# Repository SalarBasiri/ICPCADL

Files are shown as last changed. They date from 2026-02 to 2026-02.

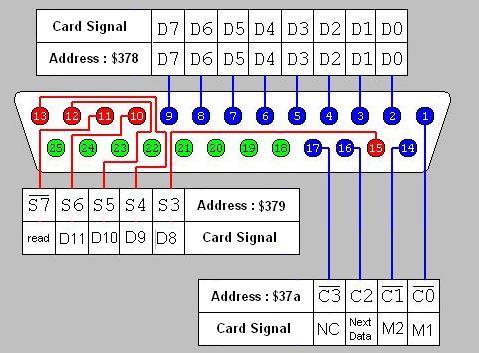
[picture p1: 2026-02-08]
Docs/Pictures/pinout.jpg

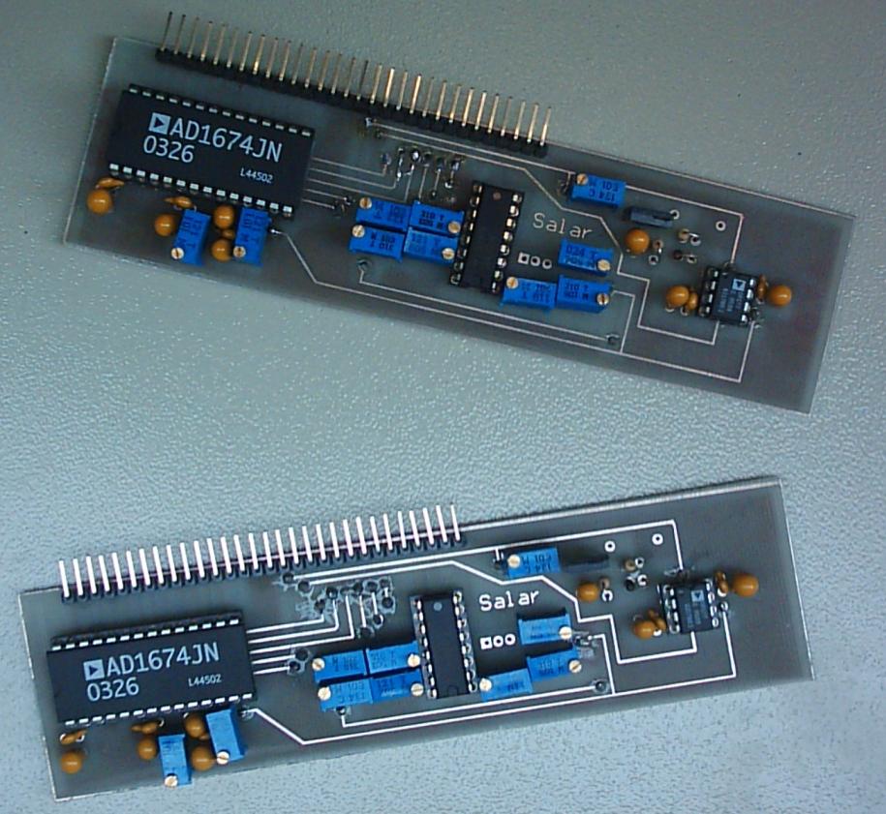
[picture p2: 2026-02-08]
Docs/Pictures/Fig3-5.JPG

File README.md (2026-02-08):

# 8-Channel Synchronous ICP Accelerometer Datalogger

## 📌 Project Overview

Developed in **2005** at **Guilan University**, this project was commissioned by the **Civil Engineering Department** to monitor structural vibrations and seismic behavior in scale models. The system is a complete mechatronics solution featuring custom signal conditioning, multi-MCU firmware, and a Delphi-based control interface.

🎥 [**Watch the System Demonstration on YouTube**](https://www.youtube.com/watch?v=GTqIrTORt20)

----------

## 📺 Demonstration Highlights

The linked video demonstrates the following key aspects of the project:

-   **The Test Setup:** A scale model of a building tower is mounted on a seismic shaker table controlled by an inverter [[00:19](http://www.youtube.com/watch?v=GTqIrTORt20&t=19)].
    
-   **Hardware in Action:** The ICP accelerometer is mounted on the tower, sending signals via BNC cables to the custom datalogger [[01:20](http://www.youtube.com/watch?v=GTqIrTORt20&t=80)].
    
-   **Real-time Software:** The Delphi application is shown configured for sampling, displaying real-time acceleration waveforms [[03:30](http://www.youtube.com/watch?v=GTqIrTORt20&t=210)].
    
-   **Physical Interface:** A look at the physical device featuring the LCD for standalone RMS/Peak monitoring and the 4x4 keypad [[06:06](http://www.youtube.com/watch?v=GTqIrTORt20&t=366)].

----------

## 🛠 Technical Specifications

### **Simultaneous Sample-and-Convert Architecture**

Unlike multiplexed systems, this architecture manages **8 separate AD1674 (12-bit) converters** in parallel.

-   **Synchronicity:** A central AVR "Main Controller" triggers all 8 converters simultaneously to ensure no phase lag between channels—essential for structural modal analysis [[03:05](http://www.youtube.com/watch?v=GTqIrTORt20&t=185)].
    
-   **High-Speed Transfer:** Data is pushed to the PC via the **Parallel Port (EPP Mode)** using custom assembly timing [[08:23](http://www.youtube.com/watch?v=GTqIrTORt20&t=503)].
    
-   **Sampling Rate:** Hardware supports up to **5,000 Samples per Second (5 kS/s)** per channel [[03:37](http://www.youtube.com/watch?v=GTqIrTORt20&t=217)].

### **Signal Conditioning**

-   **ICP Support:** Integrated constant current source (adjustable 2mA to 10mA) to power the internal electronics of piezoelectric sensors [[00:55](http://www.youtube.com/watch?v=GTqIrTORt20&t=55)].
    
-   **Programmable Gain:** Gain levels from **1 to 2200** are software-selectable, managed by a dedicated AVR controller and CD4051 analog muxes [[04:10](http://www.youtube.com/watch?v=GTqIrTORt20&t=250)].
    
-   **Digital Filtering:** The software includes an **FIR (Finite Impulse Response)** filter with a selectable cutoff frequency (8Hz to 500Hz) to eliminate high-frequency noise [[04:45](http://www.youtube.com/watch?v=GTqIrTORt20&t=285)].

----------

## 📁 Repository Structure

-   `/Software_Delphi`: Source code for the Windows XP desktop application.
    
-   `/Firmware_AVR`: BASCOM source code for the three-controller architecture (Main, Gain, and LCD/UI) [[06:58](http://www.youtube.com/watch?v=GTqIrTORt20&t=418)].
    
-   `/Hardware_Design`: Schematics and PCB layouts.
    
-   `/Docs`: The original Khwarizmi Young Award report and technical paper.

----------

## ⚠️ Legacy Note

This system was designed for Windows XP. It utilizes the **PortTalk** driver (`porttalk.sys` and `allowio.exe`) to perform direct hardware I/O via the Parallel Port [[08:23](http://www.youtube.com/watch?v=GTqIrTORt20&t=503)]. Modern 64-bit Windows versions will require hardware-level emulation or legacy environments to run the software.

----------

## 🎓 Credits

-   **Developer:** Salar Basiri (Mechanical Engineering)
    
-   **Supervision:** Dr. Fallah, Guilan University [[09:50](http://www.youtube.com/watch?v=GTqIrTORt20&t=590)]
    
-   **Partnership:** Faculty of Engineering, Civil Engineering Department

**Security & Licensing Implementation:** The production version of the software featured a custom-built hardware USB lock (Dongle) system to restrict usage to authorized workstations at Guilan University. A "Debug/Unlocked" version is included in this repository for archival and demonstration purposes.

---

## ⚖️ License & Copyright

Copyright (c) 2005-2024 Salar Basiri

This project is licensed under the **MIT License**. 

Permission is hereby granted, free of charge, to any person obtaining a copy of this software and associated documentation files (the "Software"), to deal in the Software without restriction, including without limitation the rights to use, copy, modify, merge, publish, distribute, sublicense, and/or sell copies of the Software, and to permit persons to whom the Software is furnished to do so, subject to the following conditions:

The above copyright notice and this permission notice shall be included in all copies or substantial portions of the Software.

THE SOFTWARE IS PROVIDED "AS IS", WITHOUT WARRANTY OF ANY KIND, EXPRESS OR IMPLIED, INCLUDING BUT NOT LIMITED TO THE WARRANTIES OF MERCHANTABILITY, FITNESS FOR A PARTICULAR PURPOSE AND NONINFRINGEMENT.

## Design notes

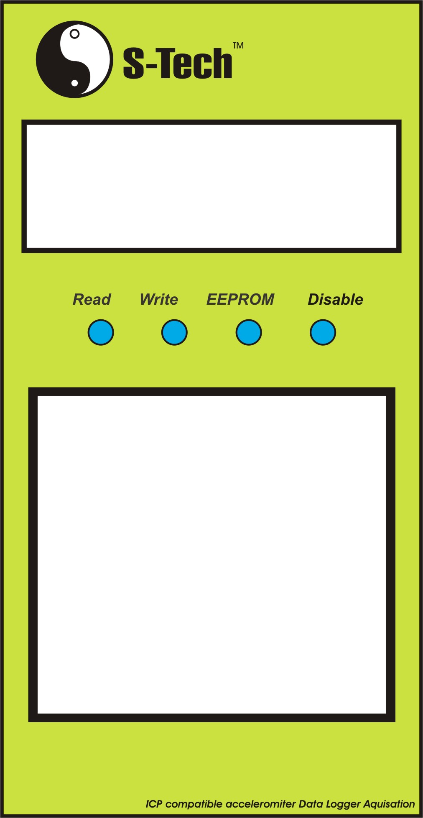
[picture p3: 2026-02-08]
Hardware_Design/Panel/Graphic1.jpg

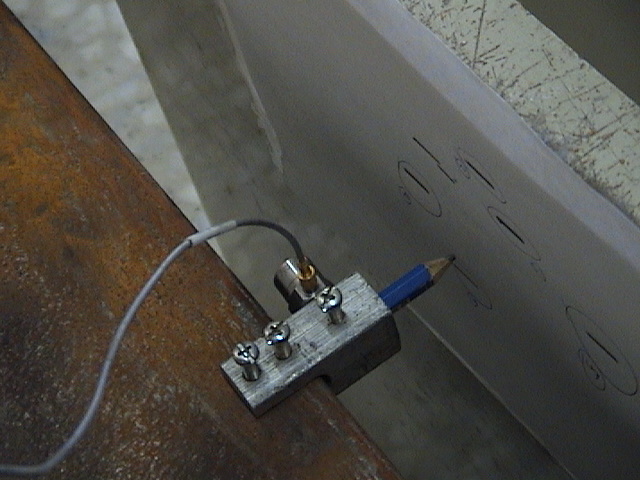
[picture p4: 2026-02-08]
Docs/Pic By Handy CAM/Copy of DSC00218.JPG

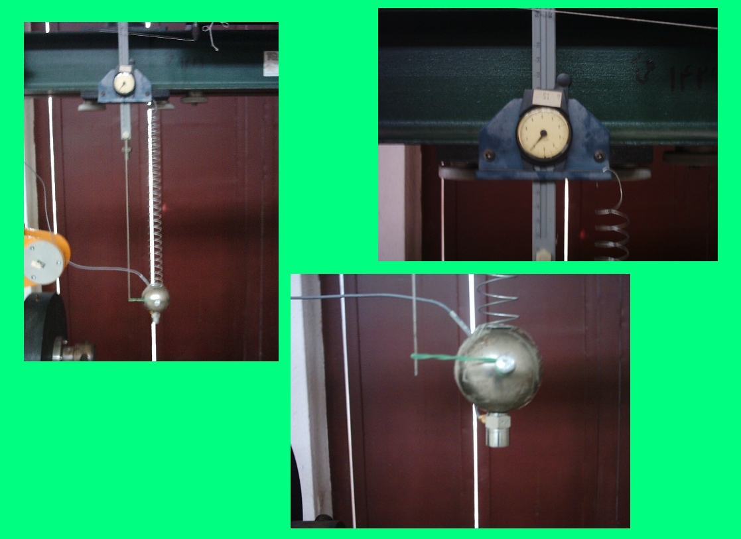
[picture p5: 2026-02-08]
Docs/Pictures/Fig5-1e.JPG

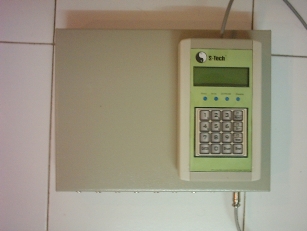
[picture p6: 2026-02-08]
Docs/Pictures/Fig-1.JPG

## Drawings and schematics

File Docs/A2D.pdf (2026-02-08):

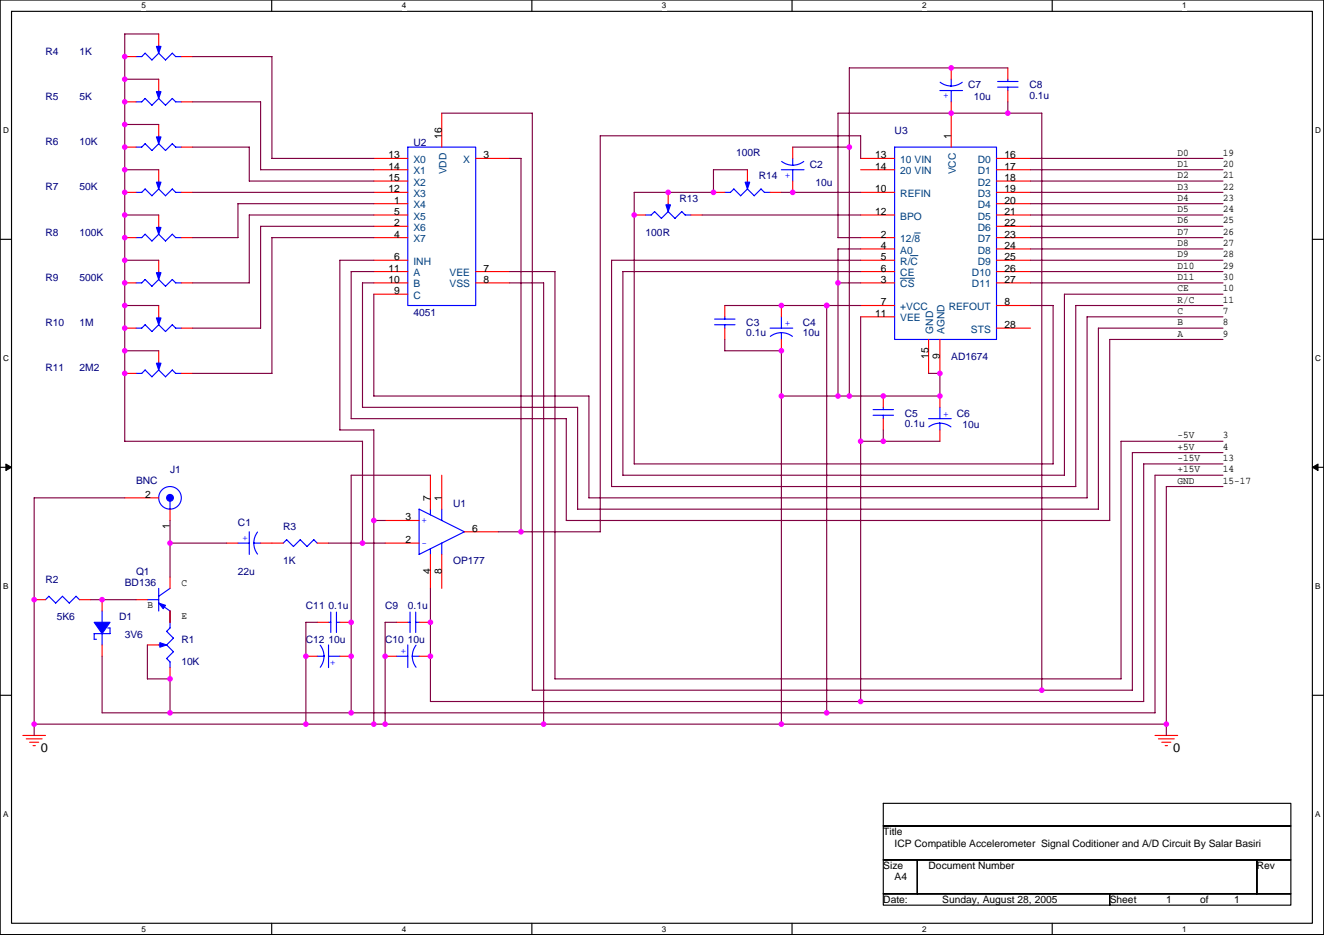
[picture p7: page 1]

Title
ICP Compatible Accelerometer Signal Coditioner and A/D Circuit By Salar Basiri

Size A4 | Document Number | Rev

Date: Sunday, August 28, 2005 | Sheet 1 of 1

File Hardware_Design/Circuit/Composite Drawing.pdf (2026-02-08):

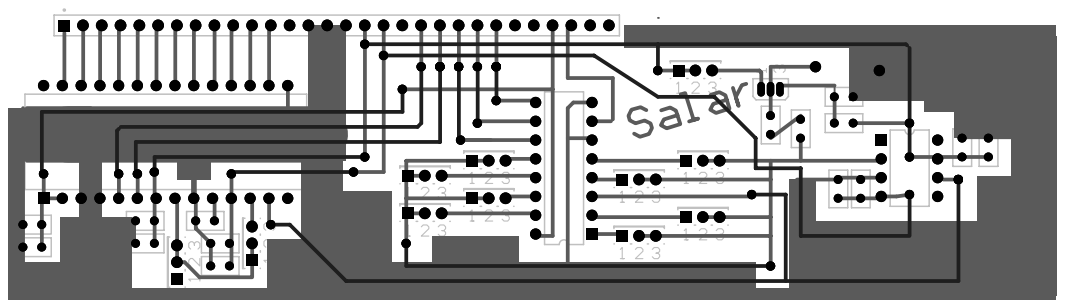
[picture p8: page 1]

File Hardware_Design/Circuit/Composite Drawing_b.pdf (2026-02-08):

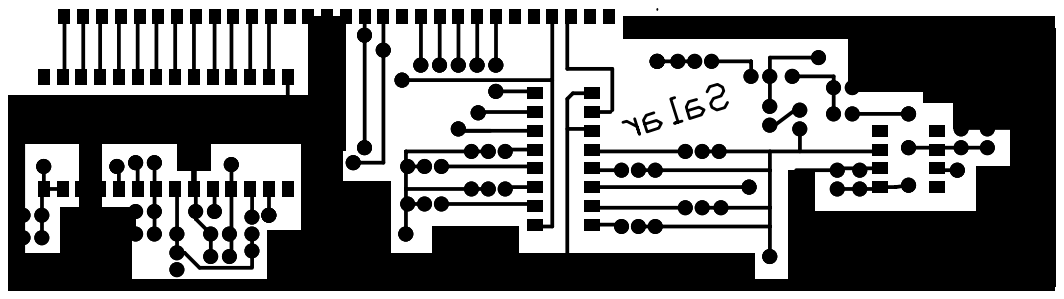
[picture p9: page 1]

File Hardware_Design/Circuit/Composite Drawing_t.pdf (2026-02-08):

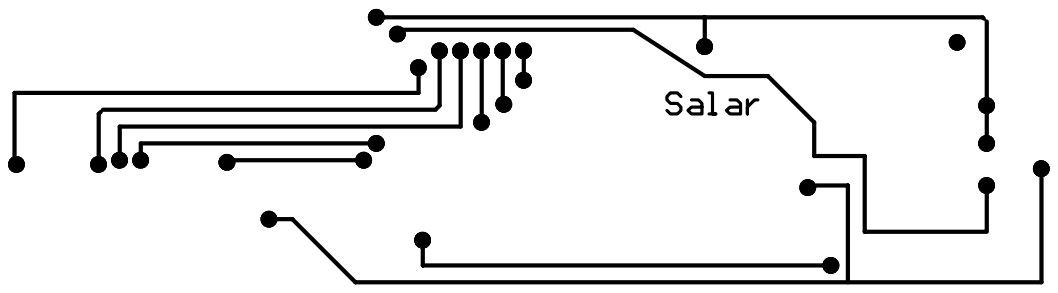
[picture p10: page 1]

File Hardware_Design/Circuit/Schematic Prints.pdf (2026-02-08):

# Power

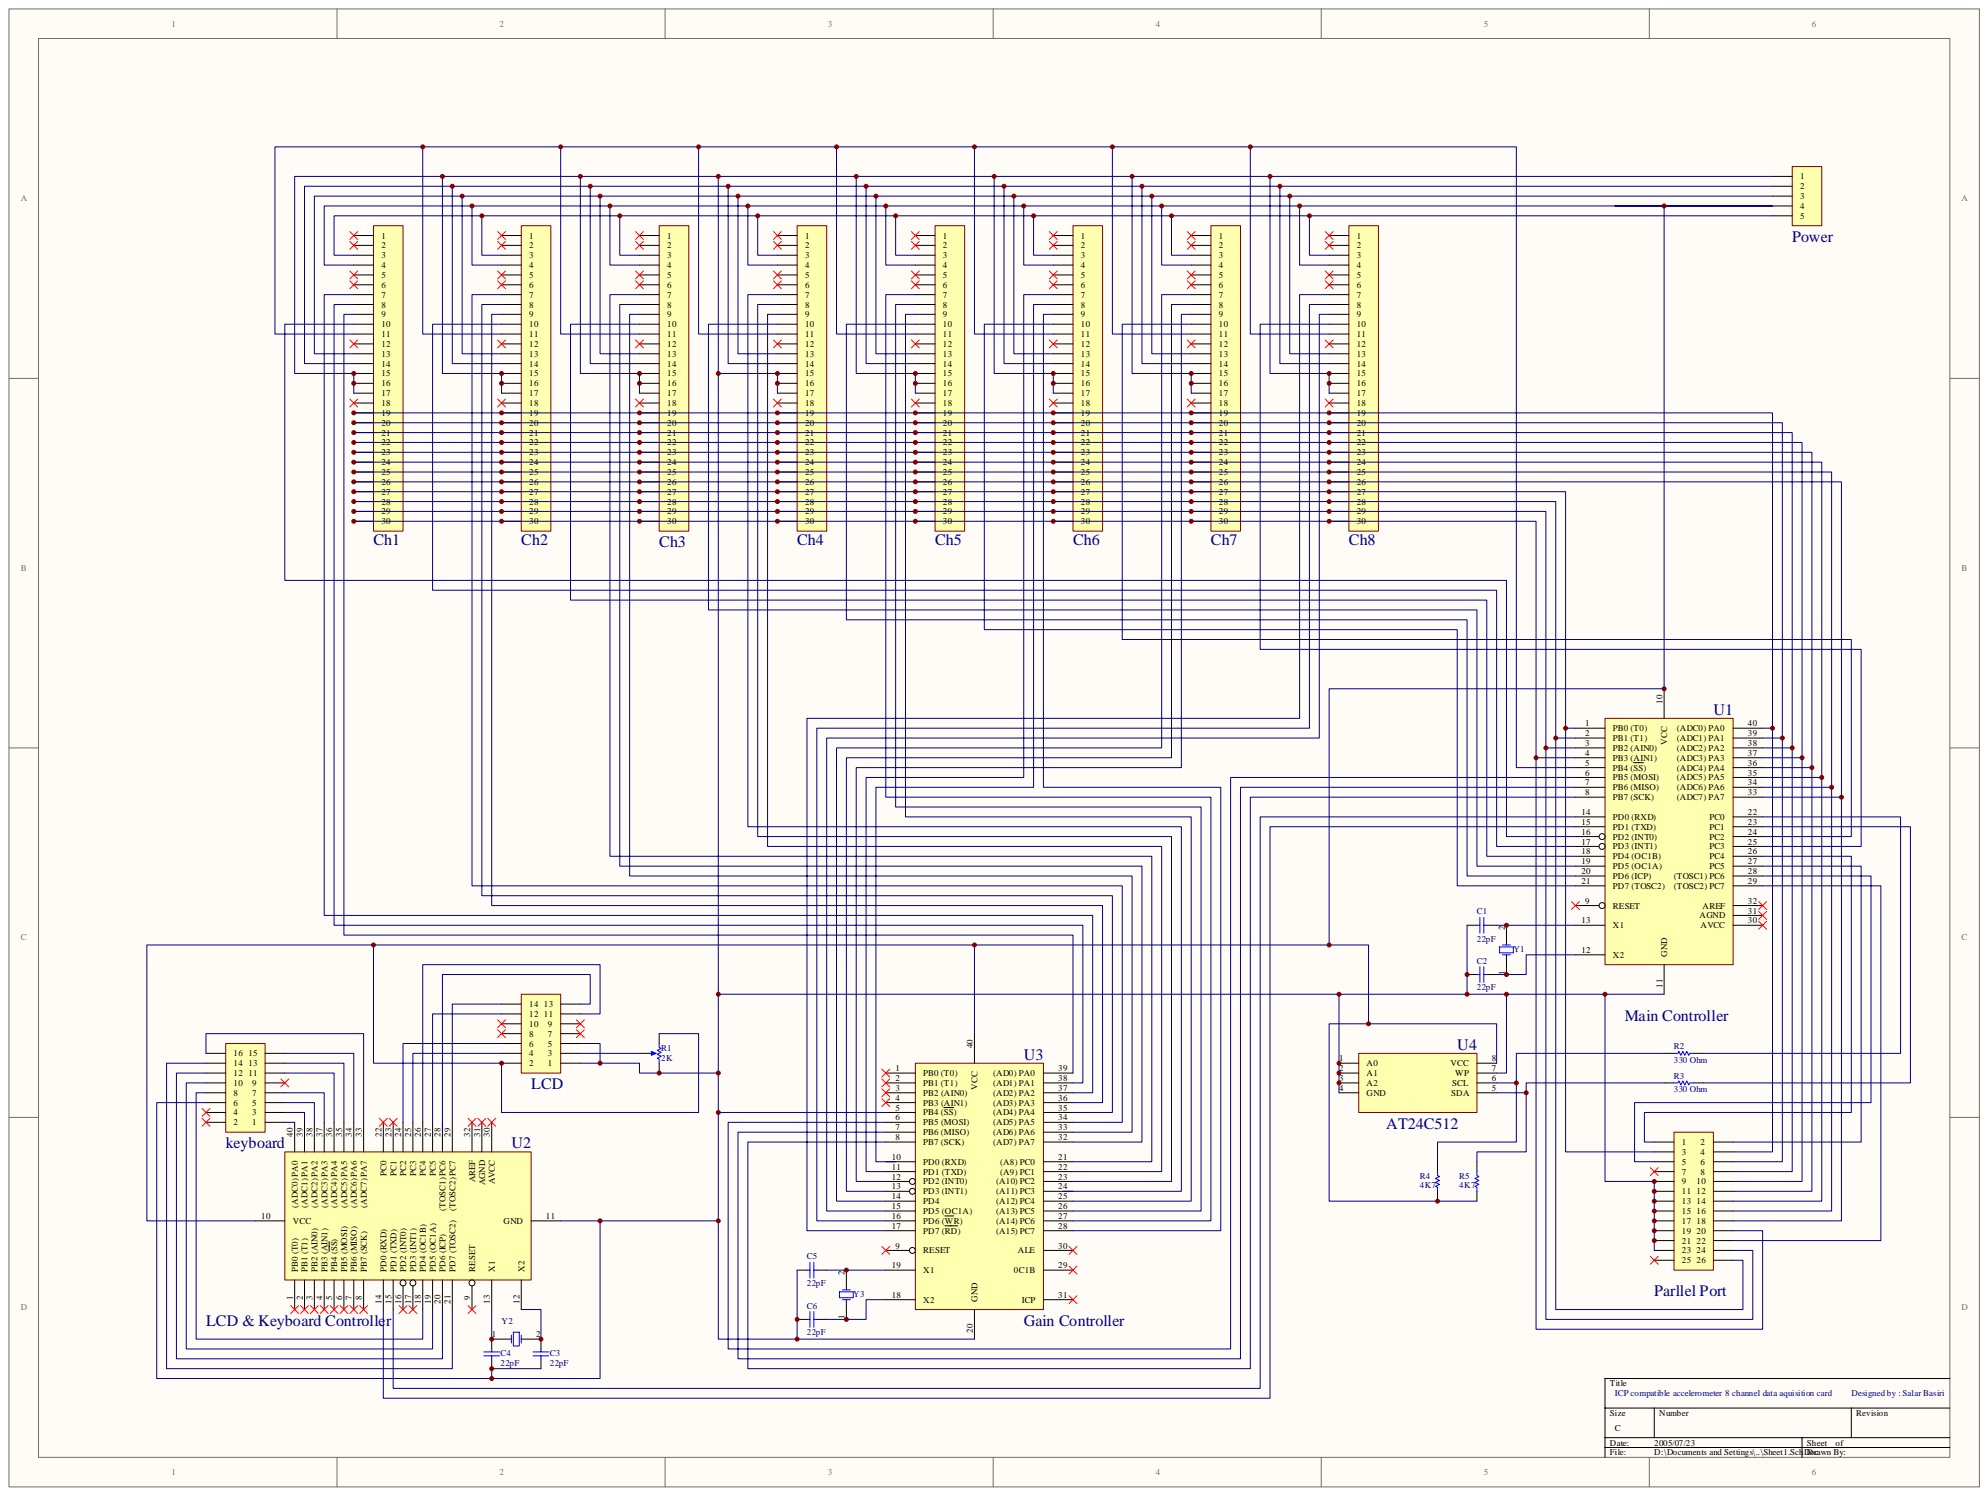
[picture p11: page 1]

20 | 20 | | 20 | | 20 | 20 | | 20 | 20 | 20
21 | 21 | 21 | 21 | 21 | 21 | 21 | 21
22 | 22 | | 22 | | 22 | 22 | | 22 | 22 | 22
23 | 23 | 23 | 23 | 23 | 23 | 23 | 23
24 | 24 | | 24 | | 24 | 24 | | 24 | 24 | 24
25 | 25 | 25 | 25 | 25 | 25 | 25 | 25
26 | 26 | | 26 | | 26 | 26 | | 26 | 26 | 26
27 | 27 | 27 | 27 | 27 | 27 | 27 | 27
28 | 28 | | 28 | | 28 | 28 | | 28 | 28 | 28
29 | 29 | 29 | 29 | 29 | 29 | 29 | 29
30 | 30 | | 30 | | 30 | 30 | | 30 | 30 | 30

C | | PB3 (AIN1) 4 | (ADC3) PA3 (ADC4) PA4 (ADC7) PA7 PC0 PC1 PC3 PC4 PC5 (TOSC1) PC6 (TOSC2) PC7 | 37 29 PD7 (TOSC2) 21 | C

PB2 (AIN0) 3 | 38

(ADC2) PA2

PB6 (MISO) 7
PB7 (SCK) 8 | 33

PD1 (TXD) 15 PD0 (RXD) 14 | 22

PD2 (INT0) 16
PD3 (INT1) 17 | 25
PD4 (OC1B) 18 | 26
PD5 (OC1A) 19 | 27
PD6 (ICP) 20 | 28

Title ICP compatible accelerometer 8 channel data aquisition card | Designed by : Salar Basiri

Size C | Number | Revision

Date: | 2005/07/23 | Sheet of
File: | D:\Documents and Settings\..\Sheet1.SchDoc Drawn By:

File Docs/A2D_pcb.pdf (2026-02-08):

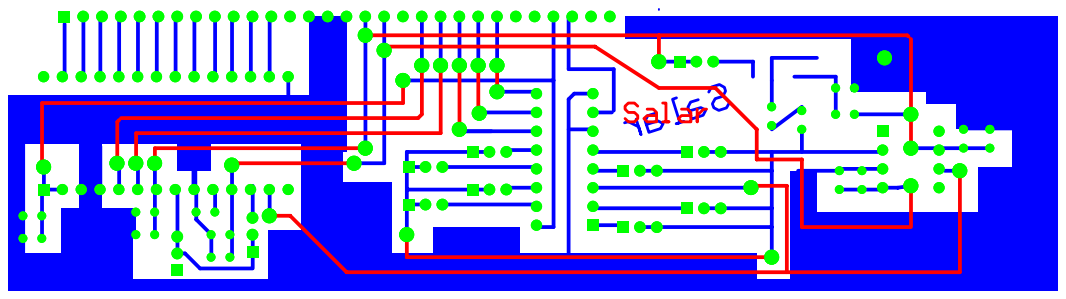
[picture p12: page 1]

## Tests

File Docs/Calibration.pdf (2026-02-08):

## تحليل فرکانسی ارتعاشات آزاد سازه مدل

در ایـن آزمـایش هـدف بدسـت آوردن فرکانـسهای مـدهای ارتعاشـی سـازه ميباشـد. سنسور شتاب به طبقات اول تا چهارم وصـل شـد و بـه طبقـه چهـارم یـک تغييـر مکـان اعمال شده و سپس رها شده است.سيگنال شتاب توسط دستگاه به مـدت ٣٠ ثانيـه جمع آوری شده و سپس توسط MATLAB تحليـل فرکانـسی در بـازه زمـانی ١٠ تـا ٢٠ ثانيه انجام گردیده است. برای تست کنالهای ورودی مختلف سنسو به کانالهای ١ و ٢ و ۶ متصل گردید و نمونه برداری انجام شد مولفه های بدست آمده به تر تيب نزولـی و برای کانالهای مختلف در زیر آمده است.

کانال ١ ١٨٫١ ١۴٫۵ ٨٫١ ٢٫۶
طبقه اول کانال ٢ ١٨٫١ ١۴٫٢ ٨٫۶ ٢٫۶ کانال ٣ ١٨٫١ ١۴٫۴ ٨٫۶ ٢٫۶
کانال ١ ١٨٫١ ٢٫۶ ٧٫٨ ١۴٫۵
طبقه دوم کانال ٢ ١٨٫١ ٢٫۶ ٨٫۶ ١۴٫۵ کانال ٣ ١٨ ٢٫۶ ٨ ١۴٫۵
کانال ١ ١٨٫١ ٢٫۶ ١۴٫٣ ٧٫٩
طبقه سوم کانال ٢ ١٨٫١ ٢٫۶ ١۴٫۴ ٧٫٩ کانال ٣ ١٨٫١ ٢٫۶ ١۴٫۵ ٧٫٩
کانال ١ ١٨٫٢ ٢٫۶ ٨ ١۴٫۵
طبقه چهارم کانال ٢ ١٨٫١ ١۴٫۴ ٢٫۶ ٧٫٨ کانال ٣ ١٨٫١ ٢٫۶ ٧٫٨ ١۴٫۴
جدول ١ – فرکانسهای موجود در سيگنال شتاب طبقات مختلف

در ادامه نمودار محتوای فرکانسی طبقات مختلف آورده شده است. تنظيمات کـارت بـه صورت زیر بوده است:
فرکانس نمونه برداری : s/S ۵٠٠٠ ضریب بهره تقویت سيگنال : ٨٠ فرکانس قطع فيلتر FIR : Hz١٠٠ زمان نمونه برداری : sec٣٠

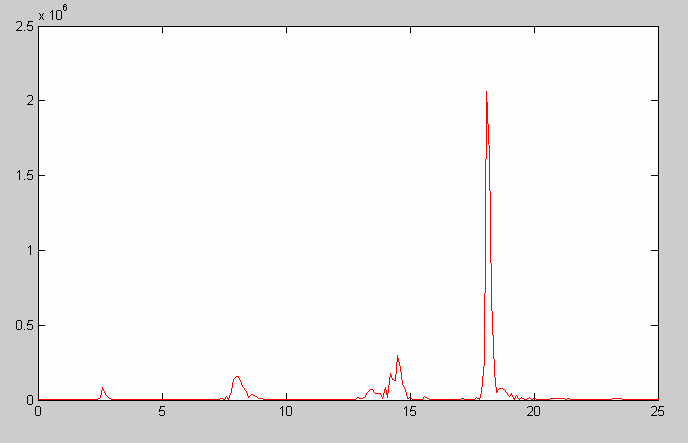
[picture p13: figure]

شکل١ - محتوی فرکانسی سيگنال شتاب طبقه اول

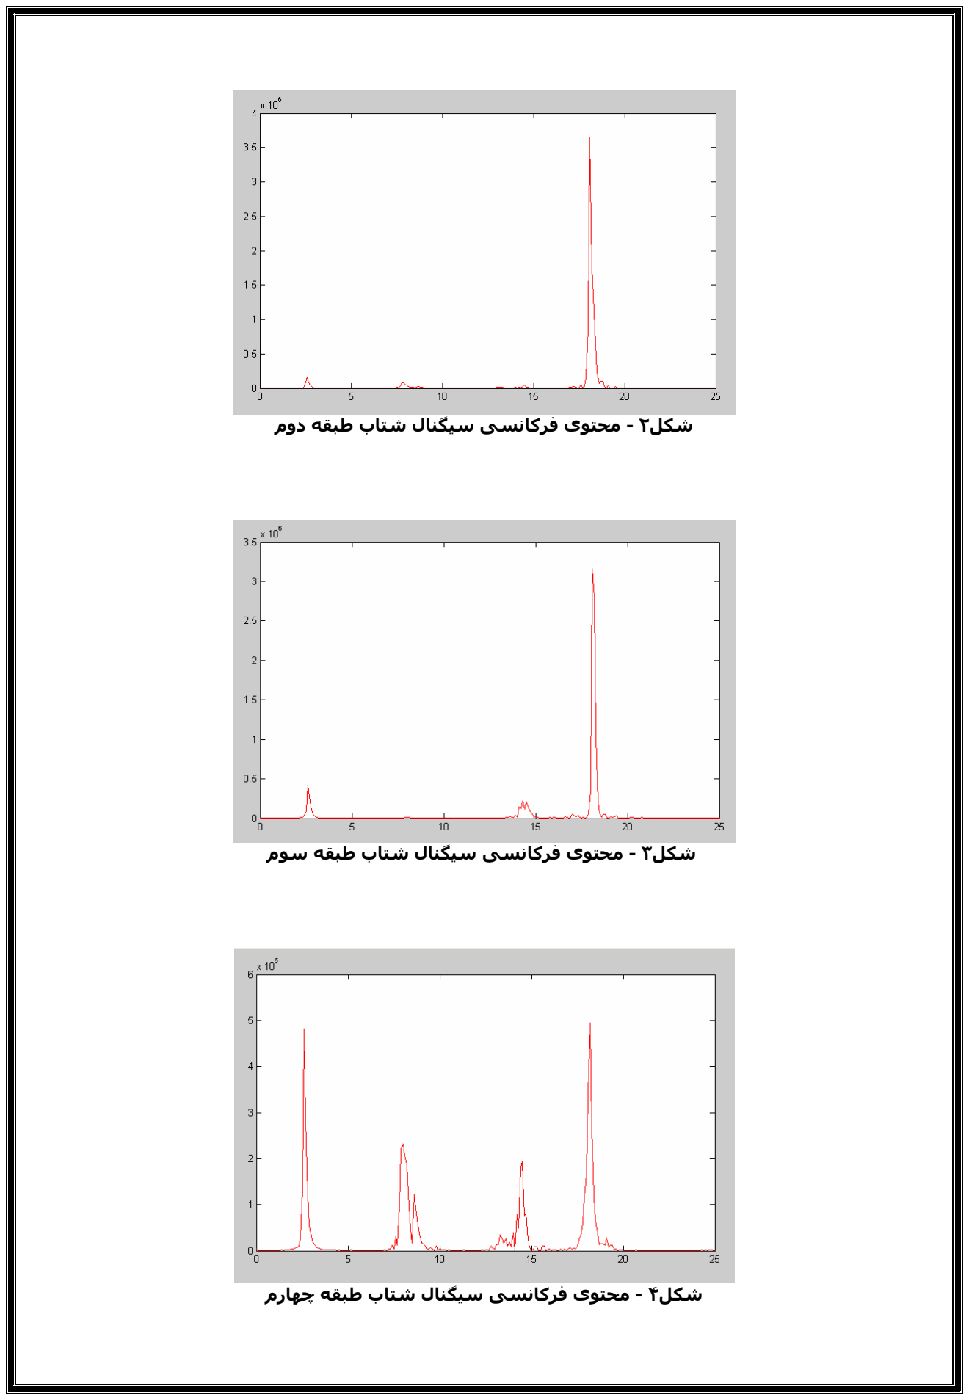
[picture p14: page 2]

شکل٢ - محتوی فرکانسی سيگنال شتاب طبقه دوم

شکل٣ - محتوی فرکانسی سيگنال شتاب طبقه سوم

شکل۴ - محتوی فرکانسی سيگنال شتاب طبقه چهارم

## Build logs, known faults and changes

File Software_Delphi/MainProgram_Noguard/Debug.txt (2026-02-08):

2005/07/19 
11:01:36 È.Ù 
Original File name: E:\New Project\Main_Program\ICPCLDL.dpr
----------------------------------------------------
  Input  string  : UNIT1.DFM
----------------------------------------------------
  Input  string  : UNIT2.DFM
---------------------------------------------------
Raw filenames in selection list
UNIT1.DFM
UNIT2.DFM
---------------------------------------------------

---------------------------------------------------------
Filename passed to ProcessDelphiForm :UNIT1.DFM
Filename passed back to ConvertDRM_to_TXT :UNIT1.DFM
Command string = 'COMMAND.COM /C D:\PROGRA~1\Borland\Delphi7\Bin\convert.exe UNIT1.DFM'
File conversion in ConvertDRM_to_TXT ...
   Filename$       :E:\NEWPRO~1\MAIN_P~1\UNIT1.DFM
       TextFileName:E:\NEWPRO~1\MAIN_P~1\UNIT1.TXT
 Final TextFileName:E:\NEWPRO~1\MAIN_P~1\UNIT1.TXT
Filename passed back to ProcessDelphiForm :E:\NEWPRO~1\MAIN_P~1\UNIT1.TXT

---------------------------------------------------------
Filename passed to ProcessDelphiForm :UNIT2.DFM
Filename passed back to ConvertDRM_to_TXT :UNIT2.DFM
Command string = 'COMMAND.COM /C D:\PROGRA~1\Borland\Delphi7\Bin\convert.exe UNIT2.DFM'
File conversion in ConvertDRM_to_TXT ...
   Filename$       :E:\NEWPRO~1\MAIN_P~1\UNIT2.DFM
       TextFileName:E:\NEWPRO~1\MAIN_P~1\UNIT2.TXT
 Final TextFileName:E:\NEWPRO~1\MAIN_P~1\UNIT2.TXT
Filename passed back to ProcessDelphiForm :E:\NEWPRO~1\MAIN_P~1\UNIT2.TXT

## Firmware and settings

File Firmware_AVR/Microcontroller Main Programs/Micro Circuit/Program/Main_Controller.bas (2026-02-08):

$regfile = "m32def.dat"
$crystal = 8000000
$baud = 1200
Config Serialin = Buffered , Size = 5
Config Serialout = Buffered , Size = 5
Config Timer1 = Timer , Prescale = 1
Config Spi = Hard , Interrupt = Off , Data Order = Lsb , Master = Yes_
                                   , Polarity = High , Phase = 0 , Clockrate = 128
Config Pina.0 = Input
Config Pina.1 = Input
Config Pina.2 = Input
Config Pina.3 = Input
Config Pina.4 = Input
Config Pina.5 = Input
Config Pina.6 = Input
Config Pina.7 = Input
Config Pinb.0 = Input
Config Pinb.1 = Input
Config Pinb.2 = Input
Config Pinb.3 = Input
Config Pinb.4 = Input
Config Pinb.5 = Input
Config Pinb.6 = Input
Config Pinb.7 = Input
Config Pinc.7 = Output
Config Pinc.6 = Input
Config Pinc.5 = Input
Config Pinc.4 = Input
Config Pind.2 = Output
Config Pind.3 = Output
Config Pind.4 = Output
Config Pind.5 = Output
Config Pind.6 = Output
Config Pind.7 = Output
Config Pinc.2 = Output
Config Pinc.3 = Output
Config Pinb.4 = Output

Enable Interrupts
Enable Timer1
Enable Ovf1
On Ovf1 Ovf1rtn
Spiinit
Dim C As Byte
Dim Send As Byte
Dim A As Byte
Dim D(10) As Byte
Dim Timer_start_value As Word

Timer1 = 63935

Disable Timer1
Reset Portc.7

A = Waitkey()
If A = 100 Then Goto Pc
If A = 200 Then Goto Stand_alone
Pc:

Do
If Pinc.5 = 1 Then If Pinc.4 = 0 Then Gosub Read_from_card
If Pinc.5 = 0 Then If Pinc.4 = 1 Then Gosub Write_to_card
If Pinc.5 = 1 Then If Pinc.4 = 1 Then Gosub Read_from_eeprom
If Pinc.5 = 0 Then If Pinc.4 = 0 Then Gosub Card_disable
Loop

Stand_alone:



End                                                         'end program

'*************************   Sample   ********************
Ovf1rtn:

Disable Interrupts
Timer1 = Timer_start_value
Portd = Portd And &B00000011
Reset Portc.2
Reset Portc.3
Set Portb.4

Send = 4
Portd = Portd Or Send
Set Portc.7

For C = 1 To 5
Bitwait Pinc.6 , Set
If Pinc.5 = 0 Then
If Pinc.4 = 0 Then
Send = 40
Printbin Send
Disable Timer1
Portd = Portd And &B00000011
Reset Portc.2
Reset Portc.3
Reset Portc.7
Reset Portb.4
Goto Pc
End If
End If

Shift Portd , Left , 1
Bitwait Pinc.6 , Reset
Next C

Reset Portc.7

Bitwait Pinc.6 , Set
Reset Portd.7
Set Portc.2
Bitwait Pinc.6 , Reset

Bitwait Pinc.6 , Set
Reset Portc.2
Set Portc.3
Bitwait Pinc.6 , Reset

Bitwait Pinc.6 , Set

Reset Portc.3
Reset Portb.4
Portd = Portd Or &B11111100
Set Portc.2
Set Portc.3

Bitwait Pinc.6 , Reset
Enable Interrupts



Return





'************************   read from card   ********************
Read_from_card:
If Send <> 10 Then
  Send = 10
  Printbin Send
  Enable Interrupts
  Enable Timer1


End If


Return




'************************   write to card   ********************
Write_to_card:
If Send <> 20 Then
  Send = 20
  Printbin Send

  For C = 1 To 10
    Bitwait Pinc.6 , Set
    D(c) = Pina
    Bitwait Pinc.6 , Reset
  Next C

  For C = 1 To 8
    Spiout D(c) , 1
    Waitms 100
  Next C

  Select Case D(9)
    Case 1 : Timer_start_value = 63935
    Case 2 : Timer_start_value = 61535
    Case 3 : Timer_start_value = 57535
    Case 4 : Timer_start_value = 45535
    Case 5 : Timer_start_value = 25535
  End Select



End If
Return



'************************   read from EEPROM   ********************
Read_from_eeprom:
If Send <> 30 Then
  Send = 30
  Printbin Send
End If
Return


'************************   card disable   ********************
Card_disable:
If Send <> 40 Then
  Send = 40
  Printbin Send
  Disable Timer1
  Portd = Portd And &B00000011
  Reset Portc.2
  Reset Portc.3
  Reset Portc.7
  Reset Portb.4

End If
Return

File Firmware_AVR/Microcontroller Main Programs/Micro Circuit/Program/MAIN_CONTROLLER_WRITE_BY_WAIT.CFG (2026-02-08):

[COMPILER-CHIP]
Chip=17
XRAM=0
Waitstate=0
XA=0
Stacksize=32
Framesize=16
Sstack=8

[COMPILER-OUTPUT]
Report vars=0
Optimize=0
Binary File=1
Hexadecimal File=1
Report File=1
Debug File=1
Error File=1
ASM File=0
LST File=0
OBJ File=1
SWAP File=0

[COMPILER-COMMUNICATION]
Baudrate=1200
Baudrate1=9600
Frequency=8000000

[COMPILER-I2C]
Scl=0
Sda=0

[COMPILER-LCD]
DB7=PORTB.7
DB6=PORTB.6
DB5=PORTB.5
DB4=PORTB.4
E=PORTB.3
RS=PORTB.2
LCD=1
BUS mode=0
DATA mode=0
LCD address=C000
LCD-RS=8000

[COMPILER-MISC]
Size Warning=0
1wire=PORTB.0

[COMPILER-SPI]
HW SPI=0
SPICLOCK=13
SPISS=13
SPIMOSI=14
SPIMISO=15

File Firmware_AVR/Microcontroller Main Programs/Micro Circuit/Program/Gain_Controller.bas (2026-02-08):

$regfile = "m8515.dat"
$crystal = 8000000
Config Spi = Hard , Interrupt = On , Data Order = Lsb , _
      Master = No , Polarity = High , Phase = 0 , Clockrate = 128
Config Pina.0 = Output
Config Pina.1 = Output
Config Pina.2 = Output
Config Pina.3 = Output
Config Pina.4 = Output
Config Pina.5 = Output
Config Pina.6 = Output
Config Pina.7 = Output
Config Pinc.0 = Output
Config Pinc.1 = Output
Config Pinc.2 = Output
Config Pinc.3 = Output
Config Pinc.4 = Output
Config Pinc.5 = Output
Config Pinc.6 = Output
Config Pinc.7 = Output
Config Pind.0 = Output
Config Pind.1 = Output
Config Pind.2 = Output
Config Pind.3 = Output
Config Pind.4 = Output
Config Pind.5 = Output
Config Pind.6 = Output
Config Pind.7 = Output
Dim Gain_ch(9) As Byte
Dim C As Byte , G As Byte
Enable Interrupts
Enable Spi
On Spi Setting_gain
Spiinit
'Porta = 0
'Portc = 0
'Portd = 0
Reset Porta.0
Reset Porta.1
Reset Porta.2
Reset Porta.3
Reset Porta.4
Reset Porta.5
Reset Porta.6
Reset Porta.7
Reset Portc.0
Reset Portc.1
Reset Portc.2
Reset Portc.3
Reset Portc.4
Reset Portc.5
Reset Portc.6
Reset Portc.7
Reset Portd.0
Reset Portd.1
Reset Portd.2
Reset Portd.3
Reset Portd.4
Reset Portd.5
Reset Portd.6
Reset Portd.7
C = 1
Cls
Do


Loop

End                                                         'end program


Setting_gain:
Disable Interrupts
Gain_ch(c) = Spdr
C = C + 1
If C = 9 Then
'Cls
'For G = 1 To 8
'Lcd Gain_ch(g) ; "  "
'Next G
C = 1
Spiinit
If Gain_ch(1) = 0 Then
Reset Porta.0
Reset Porta.1
Reset Porta.2
End If
If Gain_ch(1) = 1 Then
Set Porta.0
Reset Porta.1
Reset Porta.2
End If
If Gain_ch(1) = 2 Then
Reset Porta.0
Set Porta.1
Reset Porta.2
End If
If Gain_ch(1) = 3 Then
Set Porta.0
Set Porta.1
Reset Porta.2
End If
If Gain_ch(1) = 4 Then
Reset Porta.0
Reset Porta.1
Set Porta.2
End If
If Gain_ch(1) = 5 Then
Set Porta.0
Reset Porta.1
Set Porta.2
End If
If Gain_ch(1) = 6 Then
Reset Porta.0
Set Porta.1
Set Porta.2
End If
If Gain_ch(1) = 7 Then
Set Porta.0
Set Porta.1
Set Porta.2
End If
If Gain_ch(2) = 0 Then
Reset Porta.3
Reset Porta.4
Reset Porta.5
End If
If Gain_ch(2) = 1 Then
Set Porta.3
Reset Porta.4
Reset Porta.5
End If
If Gain_ch(2) = 2 Then
Reset Porta.3
Set Porta.4
Reset Porta.5
End If
If Gain_ch(2) = 3 Then
Set Porta.3
Set Porta.4
Reset Porta.5
End If
If Gain_ch(2) = 4 Then
Reset Porta.3
Reset Porta.4
Set Porta.5
End If
If Gain_ch(2) = 5 Then
Set Porta.3
Reset Porta.4
Set Porta.5
End If
If Gain_ch(2) = 6 Then
Reset Porta.3
Set Porta.4
Set Porta.5
End If
If Gain_ch(2) = 7 Then
Set Porta.3
Set Porta.4
Set Porta.5
End If
If Gain_ch(3) = 0 Then
Reset Porta.6
Reset Porta.7
Reset Portc.0
End If
If Gain_ch(3) = 1 Then
Set Porta.6
Reset Porta.7
Reset Portc.0
End If
If Gain_ch(3) = 2 Then
Reset Porta.6
Set Porta.7
Reset Portc.0
End If
If Gain_ch(3) = 3 Then
Set Porta.6
Set Porta.7
Reset Portc.0
End If
If Gain_ch(3) = 4 Then
Reset Porta.6
Reset Porta.7
Set Portc.0
End If
If Gain_ch(3) = 5 Then
Set Porta.6
Reset Porta.7
Set Portc.0
End If
If Gain_ch(3) = 6 Then
Reset Porta.6
Set Porta.7
Set Portc.0
End If
If Gain_ch(3) = 7 Then
Set Porta.6
Set Porta.7
Set Portc.0
End If
If Gain_ch(4) = 0 Then
Reset Portc.1
Reset Portc.2
Reset Portc.3
End If
If Gain_ch(4) = 1 Then
Set Portc.1
Reset Portc.2
Reset Portc.3
End If
If Gain_ch(4) = 2 Then
Reset Portc.1
Set Portc.2
Reset Portc.3
End If
If Gain_ch(4) = 3 Then
Set Portc.1
Set Portc.2
Reset Portc.3
End If
If Gain_ch(4) = 4 Then
Reset Portc.1
Reset Portc.2
Set Portc.3
End If
If Gain_ch(4) = 5 Then
Set Portc.1
Reset Portc.2
Set Portc.3
End If
If Gain_ch(4) = 6 Then
Reset Portc.1
Set Portc.2
Set Portc.3
End If
If Gain_ch(4) = 7 Then
Set Portc.1
Set Portc.2
Set Portc.3
End If
If Gain_ch(5) = 0 Then
Reset Portc.4
Reset Portc.5
Reset Portc.6
End If
If Gain_ch(5) = 1 Then
Set Portc.4
Reset Portc.5
Reset Portc.6
End If
If Gain_ch(5) = 2 Then
Reset Portc.4
Set Portc.5
Reset Portc.6
End If
If Gain_ch(5) = 3 Then
Set Portc.4
Set Portc.5
Reset Portc.6
End If
If Gain_ch(5) = 4 Then
Reset Portc.4
Reset Portc.5
Set Portc.6
End If
If Gain_ch(5) = 5 Then
Set Portc.4
Reset Portc.5
Set Portc.6
End If
If Gain_ch(5) = 6 Then
Reset Portc.4
Set Portc.5
Set Portc.6
End If
If Gain_ch(5) = 7 Then
Set Portc.4
Set Portc.5
Set Portc.6
End If
If Gain_ch(6) = 0 Then
Reset Portc.7
Reset Portd.0
Reset Portd.1
End If
If Gain_ch(6) = 1 Then
Set Portc.7
Reset Portd.0
Reset Portd.1
End If
If Gain_ch(6) = 2 Then
Reset Portc.7
Set Portd.0
Reset Portd.1
End If
If Gain_ch(6) = 3 Then
Set Portc.7
Set Portd.0
Reset Portd.1
End If
If Gain_ch(6) = 4 Then
Reset Portc.7
Reset Portd.0
Set Portd.1
End If
If Gain_ch(6) = 5 Then
Set Portc.7
Reset Portd.0
Set Portd.1
End If
If Gain_ch(6) = 6 Then
Reset Portc.7
Set Portd.0
Set Portd.1
End If
If Gain_ch(6) = 7 Then
Set Portc.7
Set Portd.0
Set Portd.1
End If
If Gain_ch(7) = 0 Then
Reset Portd.2
Reset Portd.3
Reset Portd.4
End If
If Gain_ch(7) = 1 Then
Set Portd.2
Reset Portd.3
Reset Portd.4
End If
If Gain_ch(7) = 2 Then
Reset Portd.2
Set Portd.3
Reset Portd.4
End If
If Gain_ch(7) = 3 Then
Set Portd.2
Set Portd.3
Reset Portd.4
End If
If Gain_ch(7) = 4 Then
Reset Portd.2
Reset Portd.3
Set Portd.4
End If
If Gain_ch(7) = 5 Then
Set Portd.2
Reset Portd.3
Set Portd.4
End If
If Gain_ch(7) = 6 Then
Reset Portd.2
Set Portd.3
Set Portd.4
End If
If Gain_ch(7) = 7 Then
Set Portd.2
Set Portd.3
Set Portd.4
End If
If Gain_ch(8) = 0 Then
Reset Portd.5
Reset Portd.6
Reset Portd.7
End If
If Gain_ch(8) = 1 Then
Set Portd.5
Reset Portd.6
Reset Portd.7
End If
If Gain_ch(8) = 2 Then
Reset Portd.5
Set Portd.6
Reset Portd.7
End If
If Gain_ch(8) = 3 Then
Set Portd.5
Set Portd.6
Reset Portd.7
End If
If Gain_ch(8) = 4 Then
Reset Portd.5
Reset Portd.6
Set Portd.7
End If
If Gain_ch(8) = 5 Then
Set Portd.5
Reset Portd.6
Set Portd.7
End If
If Gain_ch(8) = 6 Then
Reset Portd.5
Set Portd.6
Set Portd.7
End If
If Gain_ch(8) = 7 Then
Set Portd.5
Set Portd.6
Set Portd.7
End If




'Porta = 0
'Portc = 0
'Portd = 0
'G = Gain_ch(1)
'Porta = Porta Or G
'G= Gain_ch(2)
'Shift G , Left , 3
'Porta = Porta Or G
'G= Gain_ch(4)
'Shift G , Left , 1
'Portc = Portc Or G
'G= Gain_ch(5)
'Shift G , Left , 4
'Portc = Portc Or G
'G= Gain_ch(7)
'Shift G , Left , 2
'Portd = Portd Or G
'G= Gain_ch(8)
'Shift G , Left , 5
'Portd = Portd Or G
'G= Gain_ch(3)
'If G < 4 Then
'Shift G , Left , 6
'Porta = Porta Or G
''Else
'Shift G , Left , 6
'Porta = Porta Or G
'Set Portc.0
'End If
'G = Gain_ch(6)
'Shift G , Left , 7
'Portc = Portc Or G
'G= Gain_ch(6)
'Shift G , Right , 1
'Portd = Portd Or G
End If
Enable Interrupts
Return

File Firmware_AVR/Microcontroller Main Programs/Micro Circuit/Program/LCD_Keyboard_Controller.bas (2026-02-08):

$regfile = "m32def.dat"
$crystal = 8000000
$baud = 1200
Config Lcdpin = Pin , Db4 = Pinc.4 , Db5 = Pinc.5 , Db6 = Pinc.6_
                                , Db7 = Pinc.7 , E = Pinc.2 , Rs = Pinc.3
Config Lcd = 20 * 4
Config Kbd = Porta
Config Serialout = Buffered , Size = 5
Config Serialin = Buffered , Size = 5
Config Pind.4 = Output
Config Pind.5 = Output
Config Pind.6 = Output
Config Pind.7 = Output
Enable Interrupts
Declare Sub Start_graph
Dim Key As Byte
Dim C As Byte
Call Start_graph
Wait 5
Start_condition:
Locate 2 , 2
Lcd "Select Mode:    "
Locate 3 , 2
Lcd "1:PC 2:Stand alone"
Main:
Key = Getkbd()
If Key > 15 Then Goto Main
If Key = 0 Then Goto Pc
If Key = 4 Then Goto Stand_alone
'*************************   PC   ***************************
Pc:
C = 100
Printbin C
Locate 2 , 2
Lcd " Connect to PC... "
Locate 3 , 2
Lcd "   Run Program    "
Reset Portd.4
Reset Portd.5
Reset Portd.6
Set Portd.7
Do
C = Waitkey()
If C = 10 Then
Set Portd.4
Reset Portd.5
Reset Portd.6
Reset Portd.7
End If
If C = 20 Then
Reset Portd.4
Set Portd.5
Reset Portd.6
Reset Portd.7
End If
If C = 30 Then
Reset Portd.4
Reset Portd.5
Set Portd.6
Reset Portd.7
End If
If C = 40 Then
Reset Portd.4
Reset Portd.5
Reset Portd.6
Set Portd.7
End If


Loop


Stand_alone:
C = 200
Printbin C
Cls
Lcd "Under Constraction"







End                                                         'end program








'***********************   Start  Graph  **********************
Sub Start_graph
Dim A As Integer
Cls
Deflcdchar 0 , 32 , 15 , 8 , 11 , 10 , 10 , 10 , 10
Deflcdchar 1 , 32 , 31 , 32 , 31 , 32 , 32 , 32 , 32
Deflcdchar 2 , 32 , 30 , 2 , 26 , 10 , 10 , 10 , 10
Deflcdchar 3 , 10 , 10 , 10 , 10 , 10 , 10 , 10 , 10
Deflcdchar 4 , 10 , 10 , 10 , 10 , 10 , 10 , 10 , 10
Deflcdchar 5 , 10 , 10 , 10 , 10 , 11 , 8 , 15 , 32
Deflcdchar 6 , 32 , 32 , 32 , 32 , 31 , 32 , 31 , 32
Deflcdchar 7 , 10 , 10 , 10 , 10 , 26 , 2 , 30 , 32
Cls
Lcd Chr(0)
For A = 1 To 18
Lcd Chr(1)
Next A
Lcd Chr(2)
Locate 2 , 1
Lcd Chr(3)
Lcd "   Salar Basiri   "
Lcd Chr(4)
Locate 3 , 1
Lcd Chr(3)
Lcd "      Present     "
Lcd Chr(4)
Locate 4 , 1
Lcd Chr(5)
For A = 1 To 18
Lcd Chr(6)
Next A
Lcd Chr(7)
Cursor Off
End Sub

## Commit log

2026-02-08 Add AVR BASCOM Firmware
    [LCD_KEYBOARD_CONTROLLER_SERIAL_INTERRUPT.CFG, LCD_KEYBOARD_SLAVE.CFG, MAIN_CONTROLLER_WRITE_BY_WAIT.CFG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]
2026-02-08 Add Schematic and PCB
    [Copy of PCB2.PCBDOC, Mother_Board.PCBDOC, PCB Project1.PrjPCB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]
2026-02-08 Add Delphi No-Luck Version
    [ICPCADL.cfg, ICPCLDL.cfg]
